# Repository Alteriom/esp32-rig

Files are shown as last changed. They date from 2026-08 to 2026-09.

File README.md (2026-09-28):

# esp32-rig










Hardware-in-the-loop testing for ESP32 firmware: a bank of real boards, a
Raspberry Pi beside them, and a service that flashes, runs a suite, captures
what the boards said and answers with a verdict.

Compile-only CI cannot catch what a radio does, what an OTA does, what a board
does after four hours, or what two boards do to each other. A rig can. This is
the software for one.

How a rig works: your CI builds a bundle, the rig flashes the boards, runs your suite and answers with a verdict

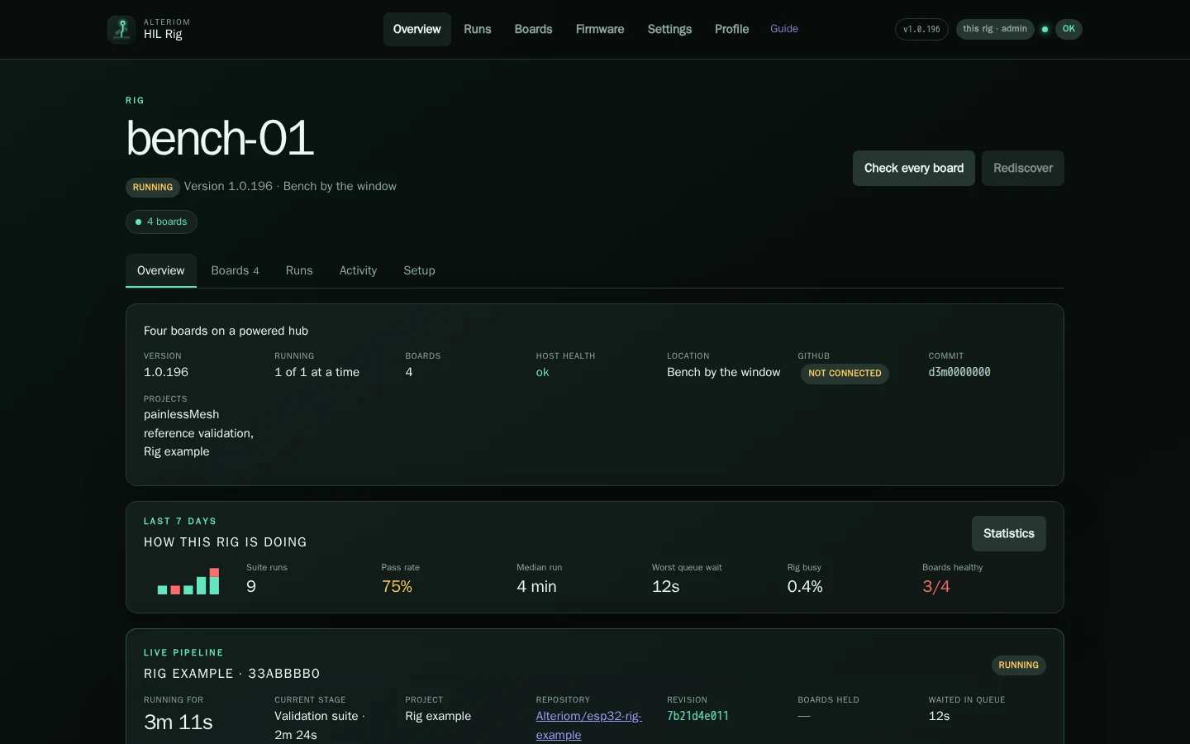
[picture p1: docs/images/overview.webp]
The rig's dashboard: its boards, its last seven days and the run in progress


Every page of the dashboard, with a picture of each:
[a tour of the dashboard](https://alteriom.github.io/esp32-rig/tour/).

## What it is

- **A service on the rig.** It queues runs, holds the boards, flashes an
  artifact your CI built, runs your suite against real hardware, captures
  every serial line and keeps the evidence. It has a dashboard.
- **A hardware abstraction layer.** Flashing, the serial console, power,
  discovery, and the pytest fixtures a suite is written against. Adding a
  board family is a description, not a rewrite.
- **A health check of its own.** Firmware the rig flashes to every board to
  answer one question before yours: is this rig fit to test on? Boots,
  serial, flash, reset, radio, wiring — per board, every release.
- **Optional: a portal.** Several rigs, one place to submit to. A rig runs
  perfectly well without one, and joining is the rig owner's choice.

## What it is not

It does not build your firmware. Your CI does that and hands the rig an
artifact with a manifest; the rig flashes exactly that and can say afterwards
precisely what it flashed. A rig with a toolchain on it is a rig that can
disagree with your CI about what "the same commit" means.

## Getting started

You need a Linux host (a Raspberry Pi 4 or 5 is what this was built on), at
least two dev boards, and a powered USB hub. **The guide** is at
[alteriom.github.io/esp32-rig](https://alteriom.github.io/esp32-rig/): [getting started](https://alteriom.github.io/esp32-rig/getting-started/)
in six steps, [what to buy and why](https://alteriom.github.io/esp32-rig/hardware/), [bring-up](https://alteriom.github.io/esp32-rig/bringup/)
in order, [the dashboard](https://alteriom.github.io/esp32-rig/dashboard/), [projects and your CI](https://alteriom.github.io/esp32-rig/projects/)
with [an example project](https://github.com/Alteriom/esp32-rig-example) to copy,
and [the API](https://alteriom.github.io/esp32-rig/api/). Its source is `docs/` here; a change to it is
published by `docs.yml`.

```bash
git clone https://github.com/Alteriom/esp32-rig
cd esp32-rig
rig/setup-runner.sh           # a virtualenv, the packages, the tools
rig/install-health-service.sh # the service, its units, udev rules
rig/verify-rig.sh             # what is missing, and what to do about it
```

Then open the dashboard, register your boards, and run the health check.

## Installing it as packages

A release is two wheels, the dashboard bundle, the Rig Health Check firmware
and a `release.json` naming each with its digest, attached to a
[GitHub release][releases]. Not PyPI yet.

```bash
base=https://github.com/Alteriom/esp32-rig/releases/download/v1.0.0
pip install   $base/alteriom_hil_core-1.0.0-py3-none-any.whl   $base/alteriom_hil-1.0.0-py3-none-any.whl
```

Both on one command line: that is what satisfies `alteriom-hil`'s dependency on
`alteriom-hil-core` without a package index.

The firmware comes with it, one bundle for every board family the rig supports,
so bringing a rig up needs no compiler and no toolchain. The firmware itself has
a repository of its own, [esp32-hil-firmware][firmware], with its own releases;
a rig release pins one (`canary/firmware.json`) and carries it. `alteriom-hil-admin
upgrade` installs and pins it, and the health check flashes what is pinned: the
same build for everyone who installs that release, which is what makes one
rig's health check comparable to another's. `--no-firmware` leaves a canary you
pinned yourself alone.

The commands it brings: `alteriom-hil-service` (the farm), `alteriom-hil-admin`
(configuration, keys, boards, providers), `alteriom-hil-health` (is this host
fit), `alteriom-hil-agent` (a rig that works for a portal), `alteriom-hil-flash`
(flash an artifact by its manifest).

A rig that already has them upgrades with the release rather than by hand:

```bash
alteriom-hil-admin upgrade --from ./dist          # a release you downloaded
alteriom-hil-admin upgrade                        # or the one your portal names
```

which checks every file against `release.json` and installs nothing if one
disagrees.

[releases]: https://github.com/Alteriom/esp32-rig/releases
[firmware]: https://github.com/Alteriom/esp32-hil-firmware
[example]: https://github.com/Alteriom/esp32-rig-example

## Writing a suite

A suite is pytest. The rig gives it a bank of boards as fixtures; what you do
with them is yours:

```python
def test_the_node_rejoins_after_a_reset(bank):
    node = bank.take("esp32-c6")
    node.reset()
    assert node.wait_for("mesh: connected", timeout=30)
```

A **profile** is the document that says where your firmware comes from, which
boards a run needs, and what to run — one file, checked in, so a run is
reproducible and a second project does not mean a second rig.

## Your project on the rig

A *project* is a GitHub repository whose firmware the rig flashes and whose
test suite it runs. A rig runs the projects it lists and no other. Two come
with the rig: the **Rig example** ([Alteriom/esp32-rig-example][example], a
small firmware and its suite -- the project to try a rig with, and to copy)
and the painlessMesh reference; both are yours to change or to remove from
the rig (and restore later). The Rig Health Check is not a project but the
rig's own firmware, installed with each release and run from Boards. Your
project needs GitHub first: the rig checks a project's repository out for
every run and fetches the firmware its CI built, and it can do neither
without a token. Give it one from the dashboard (**Settings → Rig → GitHub**,
or the Projects page while it is missing), or on the rig:

```bash
sudo alteriom-hil-admin github set     # a fine-grained token: Contents read, Actions read
sudo alteriom-hil-admin github check   # who the token is, and that GitHub accepts it
```

Until then Settings → Projects says so and offers no Add project. With it,
**Settings → Projects → Add project** asks for the repository (checked with
GitHub before anything is written), the branch a run is for by default
(empty takes the repository's own), where the pytest suite lives in it,
which chip families a run takes, and the CI workflow that builds the firmware
bundle. The rig writes the profile document under its state directory
(`/var/lib/alteriom-hil/profiles/` on a standard install), reads it back at
once, and an upgrade leaves it alone. Each project has a page there: its
configuration, the bundles the rig holds for it, its recent runs, and
**Get firmware from GitHub**, which takes the newest artifact the supply
workflow uploaded -- how a rig on a LAN, which no CI can reach, gets the
firmware its CI built. A finished run can be deleted from its page, and a
project's runs from the project's; what a run left is yours to keep or not. The same is done over the API (`GET`/`POST /api/v1/projects`,
`POST /api/v1/projects/<name>/fetch`) with an admin key. The rig does not
build firmware: your CI builds a bundle, the rig fetches it or takes it when
the CI hands it over (`POST /api/v1/artifacts`), and a run flashes it.

The rig's overview also shows the public page of the farm its software comes
from -- how many rigs and boards, how they are doing -- with a way to connect
this rig to it. Nothing there is yours; connecting is a choice, made in
Settings. `farm.public_url` in the host configuration points it at another
farm, or `off` shows none.

## Licence

Apache-2.0. The patent grant matters for a tool people run beside their own
hardware and build on.

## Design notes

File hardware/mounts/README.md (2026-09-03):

# Printable chassis

Everything that holds the rig together is generated, printable without
supports, and screws to a 330 × 272 mm base sheet (plywood, MDF, or
acrylic). Two scripts, pure Python, no dependencies:

| Script | Produces |
|---|---|
| [`generate_mounts.py`](generate_mounts.py) | the STL primitives plus `pi5-tile.stl` (Raspberry Pi 4/5, 58 × 49 hole pattern on 6 mm bosses, M2.5 screws self-tap) and `hub-strap-tile.stl` (USB hub on three zip-tie stations) |
| [`generate_chassis.py`](generate_chassis.py) | the control deck, trays and card rack described below |

STLs live in [`stl/`](stl/). Edit dimensions in the scripts and rerun
them — don't hand-edit the STLs. Holes are deliberately square: no
slicer circle-segmenting, no support, and screws and ties don't care. If
a screw hole prints tight, run the screw in once; these are self-forming
threads, not precision bores.

Why zip ties on the hub and the brick instead of screws: hubs and bricks
vary; a strap through a slot, along a groove recessed into the tile's
underside (so the tile still sits flat), and back up through the paired
slot holds any of them.

## Chassis

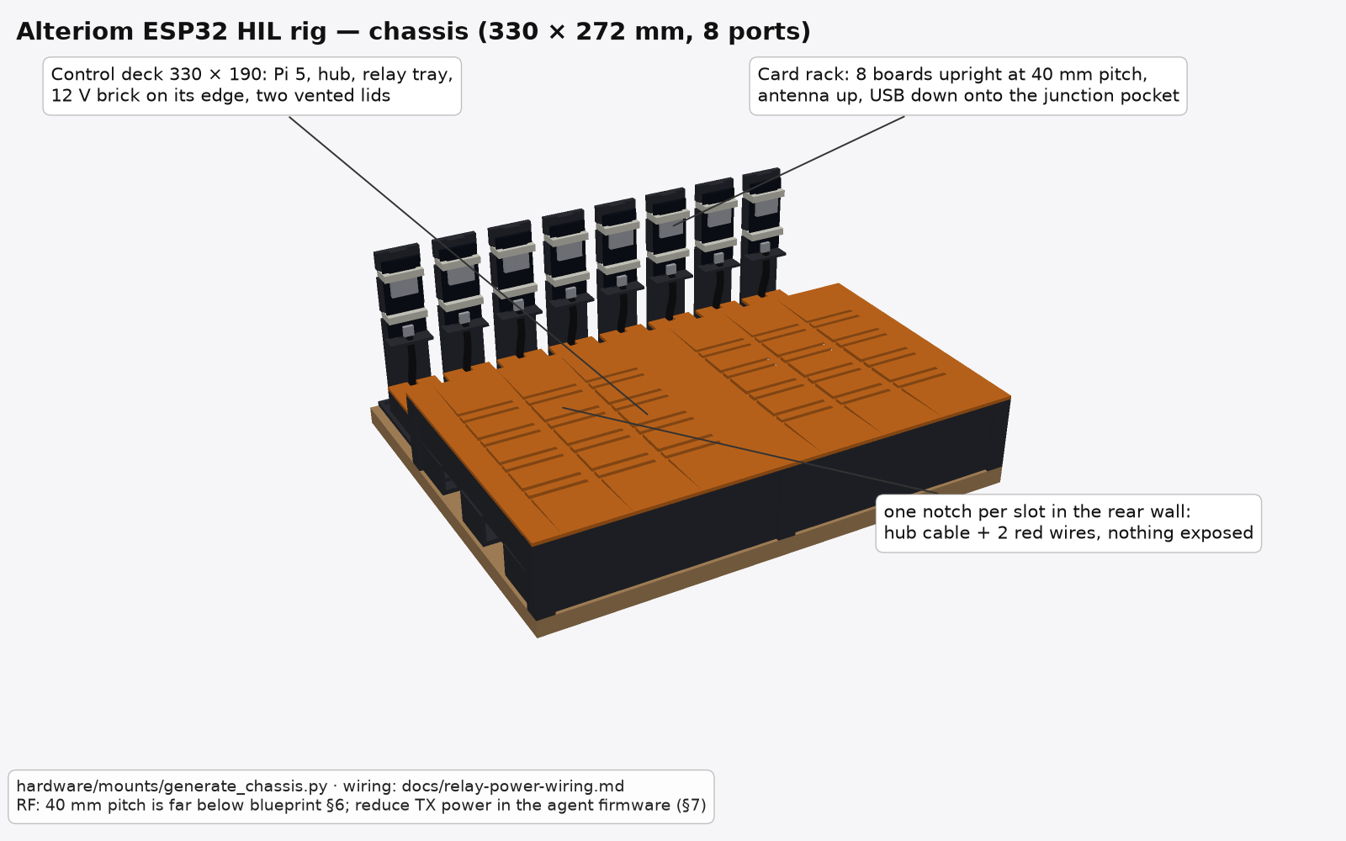
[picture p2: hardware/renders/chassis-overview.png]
Chassis overview


The relay-switched build in
[`docs/relay-power-wiring.md`](../../docs/relay-power-wiring.md) has a
relay module, a 12 V brick, sixteen red wires and a wire-nut junction per
board — the **chassis set** in [`generate_chassis.py`](generate_chassis.py)
encloses all of it. Boards stand **upright** in a card rack behind the
control deck (antenna up, USB socket down) and the brick stands **on its
edge**, so the whole eight-port rig is **330 × 272 mm** and no printed
part is longer than 178 mm (a 180 mm bed prints everything). Same rules as the tiles: pure Python, boxes only, no
supports, screw-to-base; run `python3 generate_chassis.py` after editing.

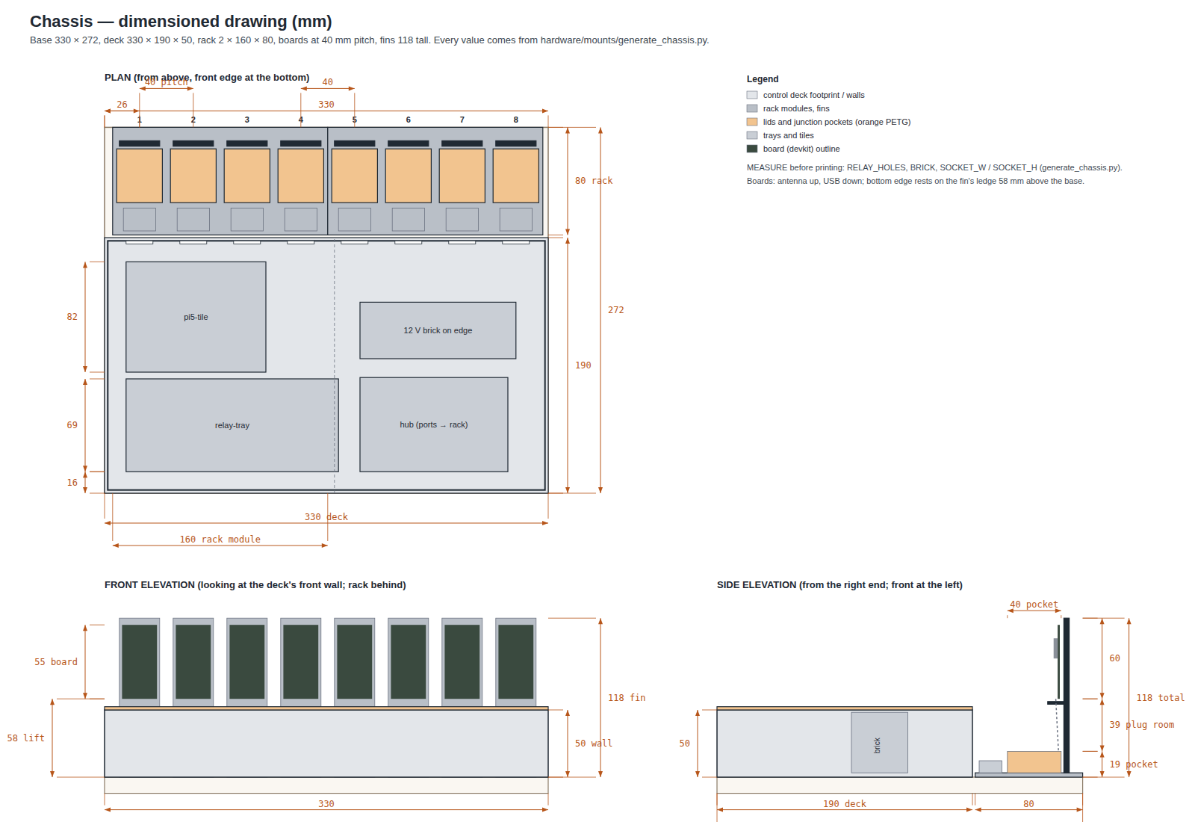
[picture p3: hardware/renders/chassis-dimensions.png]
Dimensioned drawing


Renders: [deck lids off, pockets open](../renders/chassis-deck.png) ·
[card rack](../renders/chassis-rack.png) ·
[print set](../renders/chassis-printset.png)
(from [`render_chassis.py`](../renders/render_chassis.py)); the
dimensioned drawing is [`render_dimensions.py`](../renders/render_dimensions.py),
and `python3 ../renders/build_viewer.py` writes `chassis-viewer.html`, an
interactive assembly you can orbit. All three read their numbers from the
generator.

| STL | Qty | For |
|-----|-----|-----|
| `bay-corner-post` | 4 | 12 mm post, 50 mm tall; the two walls slide into 6 mm slots; screw foot inside the corner |
| `bay-splice-post` | 2 | in-line post at the deck midline joining the two segments of a side |
| `deck-wall-long` | 2 | 159 mm front segments with a 10 mm screw flange along the inside foot |
| `deck-wall-rear` | 2 | 159 mm rear segments, one 20 × 20 mm notch per board slot: hub cable + the two red wires |
| `deck-wall-end` | 2 | 178 mm end walls, two 32 × 22 mm cable entries each (Ethernet, Pi USB-C, 12 V barrel, hub PSU) |
| `deck-lid` | 2 | 165 × 190 mm vented halves; rails underneath drop inside the walls |
| `relay-tray` | 1 | 8-channel relay module on four slotted M3 bosses (±3 mm hole-pattern tolerance) |
| `pi5-tile`, `hub-strap-tile` | 1 each | from `generate_mounts.py` |
| `psu-cradle-side` | 1 | 12 V brick standing on its long edge (100 × 30 footprint, 48 mm tall under the 50 mm wall) |
| `rack-4slot` | 2 | four upright board slots at 40 mm pitch: a 118 mm fin per board with a 12 mm rib that sits between the header rows and two strap notches, a ledge under the board's bottom edge, the junction pocket beneath it, and the USB-C socket clamp facing the deck |
| `rack-pocket-lid` | 8 | pocket lid with a notch for the male pigtail rising to the board |

**Measure before printing.** Four constants at the top of
`generate_chassis.py` are defaults for the parts in the wiring doc and
must match what you received: `RELAY_HOLES` (module hole pattern),
`BRICK` (brick length, width, thickness), `SOCKET_W` / `SOCKET_H` (the
female pigtail's overmold). Everything else is derived.

### Printing

- Structure (posts, walls, trays, rack) in a dark PETG; lids and pocket
  lids in the accent colour — the renders use charcoal and orange. Same
  0.2 mm / 3 perimeters / 20 % as the tiles; walls and lids are 2.4 mm =
  6 perimeters, so they print solid.
- **Walls**: lie on the outer face, flange pointing up. **Lids**: plate on
  the bed, rails up. **Rack**: upright, fins are 4 mm thick. **Posts**:
  upright. Nothing needs supports; the longest part is 178 mm.
- Print one `rack-4slot` first and check the socket fits its clamp, a
  board sits on the ledge with its pins clear of the fin, and the wire
  nuts clear the pocket lid before printing the second.

### Layout on the 330 × 272 mm base

Plank, MDF, or an acrylic sheet; the deck walls sit 2.4 mm in from the
edge. Coordinates are the origin (front-left corner) of each part.

| x (mm) | y (mm) | Part |
|---|---|---|
| 0–330 | 0–190 | control deck |
| 16–174 | 16–85 | `relay-tray`, terminals toward the front wall |
| 190–300 | 16–86 | `hub-strap-tile`, **ports facing the rack** |
| 16–120 | 90–172 | `pi5-tile` |
| 190–306 | 100–142 | `psu-cradle-side` |
| 6–166 and 166–326 | 192–272 | `rack-4slot` × 2; slots at x = 26 + 40·n |

Board orientation: antenna up, USB socket down, components facing the
deck. The board's bottom edge rests on the fin's ledge 58 mm above the
base so the male pigtail's plug fits between the pocket lid and the
socket. Two cable ties go around board + fin at the notches; the rib
between the header rows keeps the pins off the fin. Devkits from 25 to
29 mm wide fit; ESP8266 NodeMCU (31 mm) needs the ties only.

**RF trade-off.** Eight parallel antennas at 40 mm pitch are far denser
than blueprint §6's 0.5 m. This is the layout for flash/OTA/serial/power
coverage and bench space; for mesh-timing results, reduce TX power in the
agent firmware (§7's first RF-containment candidate) and record the
pitch in the run summary, or leave alternate slots empty for an 80 mm
pitch when a run needs it.

### Assembly

1. Screw the posts down at the deck corners and midlines, slide the walls
   in (rear segments' notches line up with the rack slots), screw every
   flange (holes every 50 mm). Cable entries on the end walls face the
   mains side.
2. Deck: relay tray front-left, hub front-right with its ports toward the
   rear wall, Pi rear-left, brick cradle rear-right, per the layout
   table. Wire the relay per the wiring doc before the lids go on; the
   GPIO ribbon and the two 12 V wires stay inside the deck.
3. Rack modules behind the rear wall, screwed to the base. Per slot: clamp
   the female pigtail (strap over it), make the wire-nut joins in the
   pocket (§6 of the wiring doc), pass the hub cable and the two red
   wires forward through the slot's notch, fit the pocket lid, strap the
   board to the fin, plug the male pigtail in from below.
4. Deck lids on. Only the boards and their antennas stand above the rig;
   every wire is under a lid.

## Scaling

One chassis = one Pi, one hub, eight ports. Growing the farm is
additive: a second chassis with its own hub on the same Pi (blueprint §8
for the per-Pi ceiling), or a second Pi runner node.

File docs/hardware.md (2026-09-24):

# Hardware

What to buy, what matters about each part, and the few rules the software
assumes you kept. A working rig is a Linux host, a powered hub, two or more
dev boards and cables that carry data. Everything else is comfort.

## The parts

| Part | What matters | Why |
|---|---|---|
| **Host**: Raspberry Pi 4 or 5 with 2 GB or more, or any small Debian or Ubuntu box | wired Ethernet; USB ports; runs Python 3.9 or newer | the rig's own Wi-Fi radio is left free for the boards to see; it reaches your LAN over the wire |
| **Host power**: the official Pi supply (27 W for a Pi 5) | never power boards from the Pi's own ports | a starved Pi throttles, and the health check will tell you so |
| **Storage**: 32 GB microSD (A2) or a small SSD | endurance is fine at this write volume | runs keep logs and serial captures; retention trims them |
| **Powered USB hub**, 7 or 8 ports, external supply of **5 V at 4 A or more** | its own supply, not the host's | boards draw more than a Pi's ports give; a starved hub is a board that "flakes" |
| **Dev boards**: esp32, esp32-c3, esp32-c5, esp32-c6, esp32-s3, esp8266, in any mix | a data-capable USB connector; see the note on two sockets below | the rig identifies each by its silicon MAC, so any family can sit on any port |
| **USB cables**, short, **data-capable**, one per board | unmodified | a charge-only cable is a board that enumerates never, or only sometimes |
| **Adapters** for micro-B boards (ESP32 DevKitC, C3-DevKitM-1, ESP8266 NodeMCU) | USB-C female to micro-B male | so every rig port can be the same |

Optional, for tests that need them:

- **Per-board power switching.** A relay module on the host's GPIO in each
  board's 5 V line, or a hub that `uhubctl` can switch. Only the power-recovery
  checks need it; reset over RTS/DTR is always available and covers most of
  what a power cut would.
- **An I/O instrument** (an ESP32 board flashed as one) wired to boards with
  jumpers, for the wiring check and for suites that drive a pin and read it
  back. See the health check page.

## Two sockets on one board

The C3, C5, C6 and S3 devkits carry two USB-C sockets: one is the chip's own
**USB-Serial/JTAG**, the other a **UART bridge**. Cable them through the one
labelled **USB**, not **UART**. A board on the UART socket still answers the
flasher during discovery, but the firmware then talks on the port the rig is
not watching, and it reads as a dead board. Discovery notes when a
native-USB family is reached through a bridge, and the health check speaks
on both, so a miscabled board is found rather than mourned.

## Rules the software assumes

- **Board identity is the silicon MAC. Port identity is the hub-port path.**
  Any family on any port; nothing is hand-labelled except, if you like, the
  port numbers on the hub. The ESP32-C5 and C6 report an 8-byte EUI-64 to the
  flasher; the rig's identity is the 6-byte base MAC.
- **Boards are USB-powered only.** Flash, serial and (with a relay) the power
  cut all ride the one USB path from hub port to board.
- **The host's Wi-Fi radio is the rig's test network.** The boards associate
  with an access point the host brings up on its own radio, so the radio
  checks prove the boards see *this* rig. Keep the host on Ethernet.
- **Antennas up, boards apart.** Boards standing upright with a few
  centimetres between them, not lying in a heap: a heap is a radio test of
  the heap.

## How many boards

Two is the minimum for anything that talks board to board. The health check
is per board and is happy with one. Six, one per family, is what the rig
software is developed against; eight is a comfortable hub.

## A chassis, if you want one

The rig this software was built on sits on a 330 × 272 mm base: a lidded
control deck for the Pi, the hub and the relay module, and a card rack that
stands eight boards upright with their antennas clear. It is about a
weekend of printing and an afternoon of assembly. Nothing in the software
depends on it; a board on a desk is a board.

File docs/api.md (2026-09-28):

# API reference

Everything the dashboard does, it does through this API, so anything you can
click you can script. JSON in and out, under `/api/v1/` on the rig (port 8090
on the host, or behind its proxy). Authenticate with a key in the
`Authorization: Bearer <key>` header. Roles: `user` reads and submits,
`admin` changes, `node` is a farm's agent.

```bash
KEY=$(sudo cat /etc/alteriom-hil/api-token)
curl -fsS -H "Authorization: Bearer $KEY" http://127.0.0.1:8090/api/v1/view | python3 -m json.tool
```

An error is `{"error": "<what went wrong, in words>"}` with a 4xx status; a
refusal by GitHub is passed through as GitHub said it.

## The rig

| | Role | Does |
|---|---|---|
| `GET /api/v1/view` | user | **the rig view**: one document with the rig's name, description, location, version, health, boards, inventory, running jobs, profiles, setup state. Contract 1. What the dashboard's rig page renders, and what a farm shows for this rig |
| `GET /api/v1/status` | user | the service's status: mode, version, queue, inventory, health, who the key is |
| `GET /api/v1/whoami` | any key | the key's name and role |
| `GET /api/v1/rig/details` | user | name, description, location |
| `POST /api/v1/rig/details` | admin | set them: `{"name", "description", "location"}` |
| `GET /api/v1/farm/public` | user | the public page of the farm the overview shows, cached; `farm.public_url: off` answers none |
| `GET /api/v1/inventory` | user | the boards and instruments as last discovered |
| `POST /api/v1/inventory/refresh` | admin | rediscover (waits for an idle rig) |
| `POST /api/v1/health` | admin | run the Rig Health Check: `{"targets": [...]}` or `{"boards": [...]}` to narrow |

## Projects

| | Role | Does |
|---|---|---|
| `GET /api/v1/projects` | user | the projects on this rig, each with its configuration, bundles and recent runs |
| `POST /api/v1/projects/inspect` | admin | `{"repo": "<url>"}`: what GitHub says about the repository, as a filled-in form with what was found and what was guessed |
| `POST /api/v1/projects` | admin | add one: `{"name", "repo", "default_ref", "suite_path", "families", "supply_workflow", "supply_artifact", "revision_key", "min_boards", "timeout_seconds"}`; everything but `repo` has a default; refused when the token cannot read the repository |
| `POST /api/v1/projects/<name>` | admin | change one, same fields |
| `POST /api/v1/projects/<name>/delete` | admin | remove it (a shipped one is tombstoned) |
| `POST /api/v1/projects/<name>/restore` | admin | bring a removed shipped project back |
| `POST /api/v1/projects/<name>/fetch` | admin | **Get firmware from GitHub**: the newest artifact of the supply workflow, checked and held; `{"reused": true}` when the rig already holds that commit |
| `POST /api/v1/projects/<name>/runs/delete` | admin | delete every finished run of the project |
| `GET /api/v1/github` | user | whether a token is set, who GitHub says it is, when it was last checked |
| `POST /api/v1/github` | admin | `{"token": "..."}`: store a token (checked with GitHub first); never shown back |
| `POST /api/v1/github/remove` | admin | forget it |

## Runs

| | Role | Does |
|---|---|---|
| `POST /api/v1/suites` | user | submit a run: `{"profile", "ref", "branch", "artifact", "targets", "boards", "tests", "keyword", "reuse", "supersede", "env", "actor"}` (on a portal also `rig`, the rig the run is for; a rig refuses it). Only `profile` matters; `ref` defaults to the project's default branch, `artifact` to the newest bundle the rig holds for that commit (none held: refused at submit, naming the workflow). Answers the run's id |
| `GET /api/v1/jobs` | user | runs, newest first, with the count behind each status: `?status=`, `?kind=` (`suite`, `inventory`), `?q=` (id, ref, summary…), `?by=` (who asked: a key's or an account's name), `?limit=`, `?offset=` |
| `GET /api/v1/jobs/<id>` | user | one run: state, stages with durations, results, the files it left |
| `GET /api/v1/jobs/<id>/artifacts/<name>` | user | one file a run left: the pipeline log, a board's serial capture, `results.xml`, the report |
| `POST /api/v1/jobs/<id>/cancel` | user | stop a queued or running run |
| `POST /api/v1/jobs/<id>/delete` | admin | delete a finished run and what it left |

A run's id is 32 hex characters. States: `queued`, `running`, `passed`,
`failed`, `cancelled`, `error`.

## Bundles

| | Role | Does |
|---|---|---|
| `GET /api/v1/artifacts` | user | the bundles the rig holds, a page at a time: id, project, commit, families, size, origin, pinned; `?profile=`, `?branch=`, `?q=`, `?limit=` |
| `GET /api/v1/artifacts/library` | user | the same, grouped by project and commit |
| `POST /api/v1/suites` | user | start a run: `{"profile", "artifact", "ref", "targets", "branch", "tests", "keyword", "boards", "rig"}`; on a portal `rig` names the rig the run is for and no other (an account's run names its own, or one shared with it); a rig, being one rig, refuses it |
| `POST /api/v1/artifacts?profile=…&repo=…&workflow=…&run_id=…&run_url=…&commit=…` | user | hand a bundle over: the body is a `.tar.gz` of the bundle directory, at most 256 MB; the query names its provenance, checked against the project's supply block; the manifest's revision key must equal `commit`. Answers the bundle's id, or `{"reused": true, ...}` for a commit already held |
| `GET /api/v1/artifacts/<id>` | user | one bundle: its manifest and provenance |
| `GET /api/v1/artifacts/<id>/bundle` · `/files/<path>` | user | download it as `.tar.gz`, or one file out of it |
| `PATCH /api/v1/artifacts/<id>/pin` · `/unpin` | admin | keep it past every prune; stop |
| `PATCH /api/v1/artifacts/<id>` | admin | `{"delete": true}`: remove one |
| `PATCH /api/v1/artifacts/prune` | admin | remove what retention would, now |

## Boards

Boards live in the inventory, which is what discovery writes.

| | Role | Does |
|---|---|---|
| `GET /api/v1/inventory` | user | every board and instrument: port, family, MAC, state, last health verdicts |
| `GET /api/v1/inventory/<board>/details` | user | the chip as the board reported it |
| `GET /api/v1/inventory/<board>/history` | user | the runs and health checks it took part in |
| `PATCH /api/v1/inventory/<board>/reserve` · `/release` | admin | `{"reason"}`: hold a board out of runs, or release it (also how quarantine is lifted) |
| `PATCH /api/v1/inventory/register` | admin | register a board by hand, as `alteriom-hil-admin boards add` does |
| `POST /api/v1/health` | admin | the Rig Health Check: `{"boards": ["<id>"]}` for one board, or nothing for all |

## Queue

| | Role | Does |
|---|---|---|
| `PATCH /api/v1/queue/pause` | admin | `{"reason": "..."}`: stop starting runs |
| `PATCH /api/v1/queue/resume` | admin | start again (a passing health check does this too) |

## Host

| | Role | Does |
|---|---|---|
| `GET /api/v1/config` | admin | the host configuration, by section, with what each setting means |
| `GET /api/v1/stats` | user | runs, pass rates and durations over time |
| `GET /api/v1/storage` · `/storage/<kind>` | user | what the rig's disk holds, by kind |
| `GET /api/v1/retention` · `PATCH /api/v1/retention/run` | admin | what retention removes on its own; run it now |
| `GET /api/v1/setup` | user | what a new rig still has to do |
| `GET /api/v1/keys` | admin | who holds a key, by name and role; never a key |
| `GET /api/v1/sessions` · `POST /api/v1/sessions/revoke` | user | the browser sessions signed in with this key; end one |

Keys themselves are made and revoked on the host:

```bash
sudo alteriom-hil-admin keys create --name ci-bundles --role user    # printed once
sudo alteriom-hil-admin keys list
sudo alteriom-hil-admin keys revoke --name ci-bundles
```

## Webhooks

| | Role | Does |
|---|---|---|
| `GET /api/v1/webhooks` | admin | where this rig's events go; the secret is never among them |
| `PATCH /api/v1/webhooks` | admin | `{"url", "secret", "events": [...]}`: add one; deliveries are signed with the secret when given |
| `PATCH /api/v1/webhooks/<id>` · `…/<id>/test` · `DELETE /api/v1/webhooks/<id>` | admin | change, send a test event, remove |
| `GET /api/v1/webhooks/<id>/deliveries` | admin | what was sent and what came back |

The same events go to the channels `alteriom-hil-admin notify` sets up.

## The command line

`alteriom-hil-admin` on the host does what the API does and a little more,
under `sudo` for anything that writes:

| Command | Does |
|---|---|
| `status` | the saved or live health snapshot |
| `config show` · `validate` · `set <key> <value>` · `apply` | the host configuration |
| `config join --portal … --token …` | make this host a node of a farm |
| `github set` · `check` · `remove` | the GitHub token |
| `keys list` · `create` · `revoke` | API keys |
| `boards list` · `discover` · `add` · `remove` · `validate` | the board registry |
| `instruments list` · `add` · `wire` · `unwire` · `probe` · `remove` | test equipment and its jumpers |
| `health refresh` | a fresh host health snapshot |
| `upgrade [--from DIR] [--no-firmware] [--dry-run]` | install a release |
| `backup create` · `list` · `restore [--apply]` | the nightly backup, by hand |
| `notify set` · `show` · `test` · `tune` · `remove` | where the rig says it broke |
| `providers set` · `show` · `check` · `test` · `remove` | real services the rig validates with your credential |
| `service` | the Actions runner service, on a rig that has one |

## The MCP server

The rig also speaks the Model Context Protocol, so an assistant can ask it
what is running, read a failure, or submit a run with the same key and the
same roles. [MCP](mcp.md) has the tools and how to connect.

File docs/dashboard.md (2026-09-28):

# The dashboard

The rig's own web page, served by the rig at port 8090 (or behind its
reverse proxy). Six pages in the header: **Overview**, **Runs**, **Boards**,
**Firmware**, **Settings** and your **Profile**. Sign in with a key; the key
stays in that browser tab and nowhere else. [A tour of the dashboard](tour.md)
shows every page with a picture.

The same pages, rendered from the same rig-view document, are what a farm
shows for this rig once it is connected. What you see here is what the farm
sees, no more.

## Overview

The Overview page

The rig's own page. Its name, description and location as written in
Settings; its version; its health in a word with what is not ok up front,
and every check behind one click; the run in progress with its live stages;
what needs attention; recent runs; the boards. **How this rig is doing** is
the last seven days in one line, and **Statistics** opens the whole history.
At the bottom, the public page of the farm the rig software comes from, with
a way to connect this rig to it. Nothing there is yours; connecting is a
choice made in Settings.

## Runs

**New run** at the top: choose the project, the bundle to flash (the ones the
rig holds for that project, newest first; **Get firmware from GitHub** on the
project's page fetches a new one), which boards or families, and under
**Test selection** a pytest keyword or a list of test files to narrow the
suite. **Run**.

Below, every run the rig has made, newest first, searchable, with its
verdict, project, commit, boards, duration and **who asked for it**, linked
to their [profile](#profile).

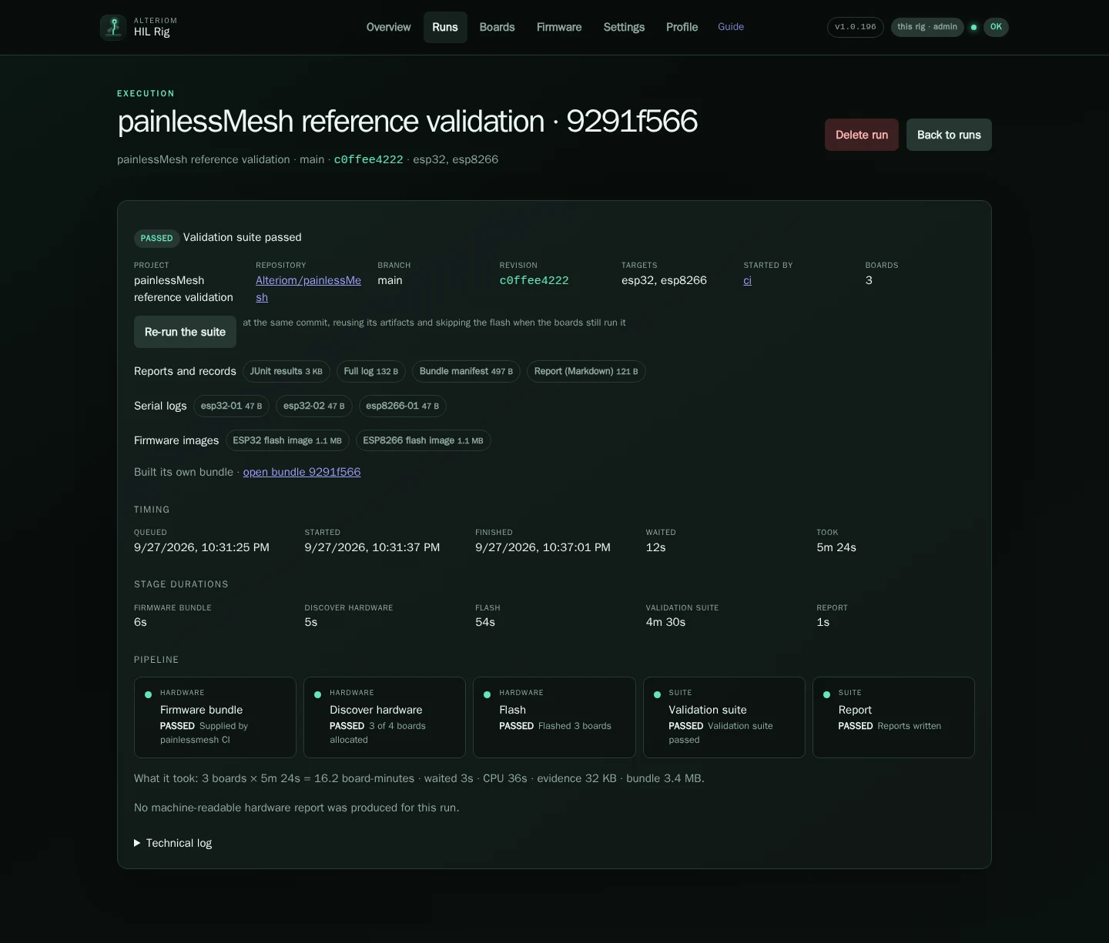
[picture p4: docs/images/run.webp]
A run's page


A run's page has:

- **the pipeline** — checkout, discover, flash, preflight, suite, report,
  each with its duration and log;
- **the results** — every test, per board where the suite is per board,
  with the failure text;
- **the evidence** — the pipeline log, one serial capture per board, the
  JUnit file, the report, each downloadable;
- **cancel** while it runs, **delete** once it has finished. What a run left
  is yours to keep or not.

The queue's state is at the top of the page: paused by a red health check
with the reason, or by you; resume from there.

## Boards

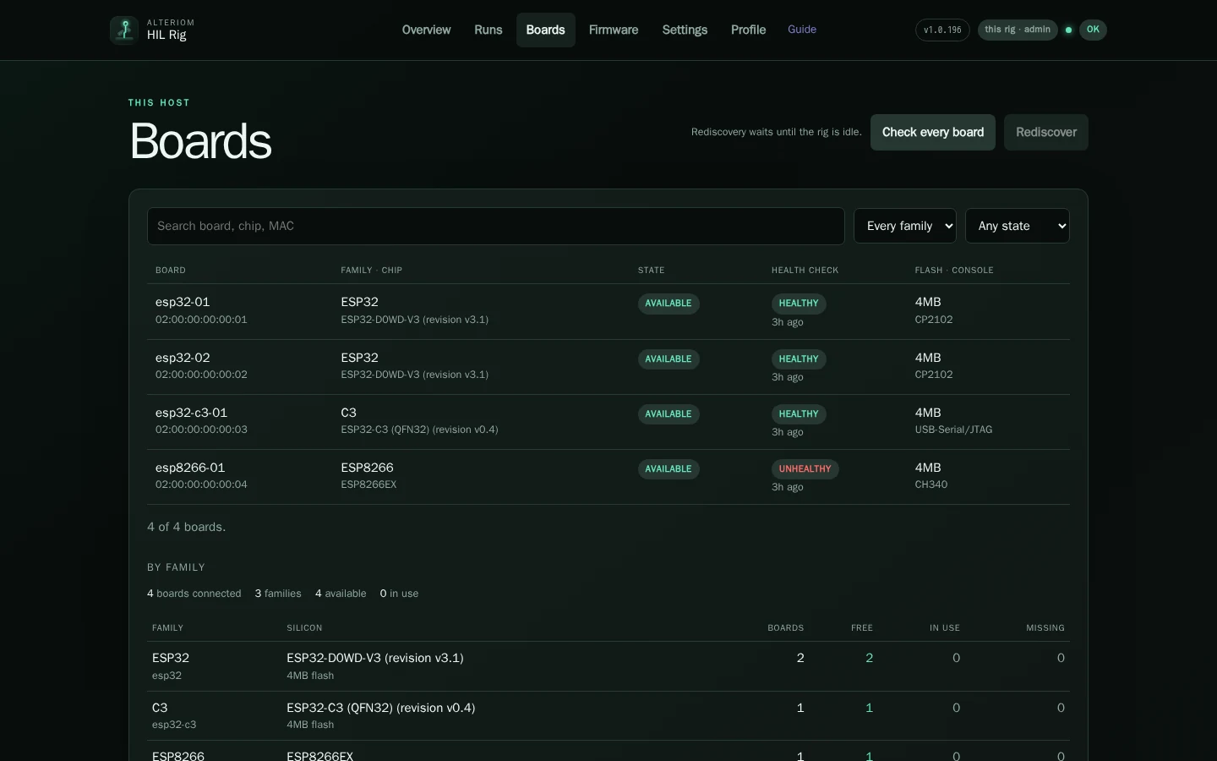
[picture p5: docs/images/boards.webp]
The Boards page


Every board the rig knows: name (family and the last four characters of
its MAC), family, port, state (idle, held by a run, quarantined, red on a
check), the last health check's verdict per check, and the chip it reported
(model, revision, cores, flash size). Filter by family and state; search.

**Rediscover** opens every port and reads every chip again; it waits for the
rig to be idle, since a discovery resets boards a run may be holding.
**Run the Rig Health Check** checks every board. A board's own page has its
chip in full, its health check history, the runs it took part in, and a check
of that one board.

Instruments (test equipment wired to boards) appear here too, with their
wiring. Register one with `alteriom-hil-admin instruments add`, and each
jumper with `instruments wire`.

## Firmware

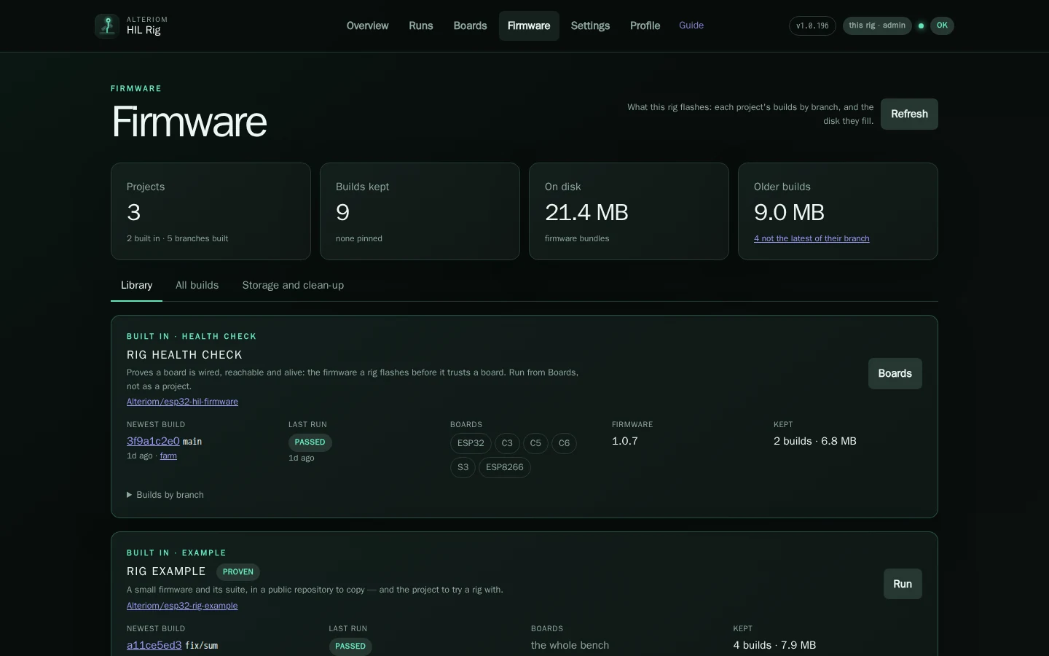
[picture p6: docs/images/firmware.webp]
The Firmware page


**Library** is one card per project: the newest build of each branch and who
it came from, the last run on it, the families it holds and what it keeps on
disk. **All builds** is every bundle the rig holds, one row each: the project,
the commit, the families, the size, when it arrived and how (fetched from
GitHub, handed over by a CI, installed with a release), and whether it is
**pinned**. The health check's bundle is pinned by the release that installed
it. **Storage and clean-up** says what older builds cost and prunes them:
retention removes old unpinned bundles, and a pinned one outlives every
prune. Download a bundle or delete one from its page.

## Statistics

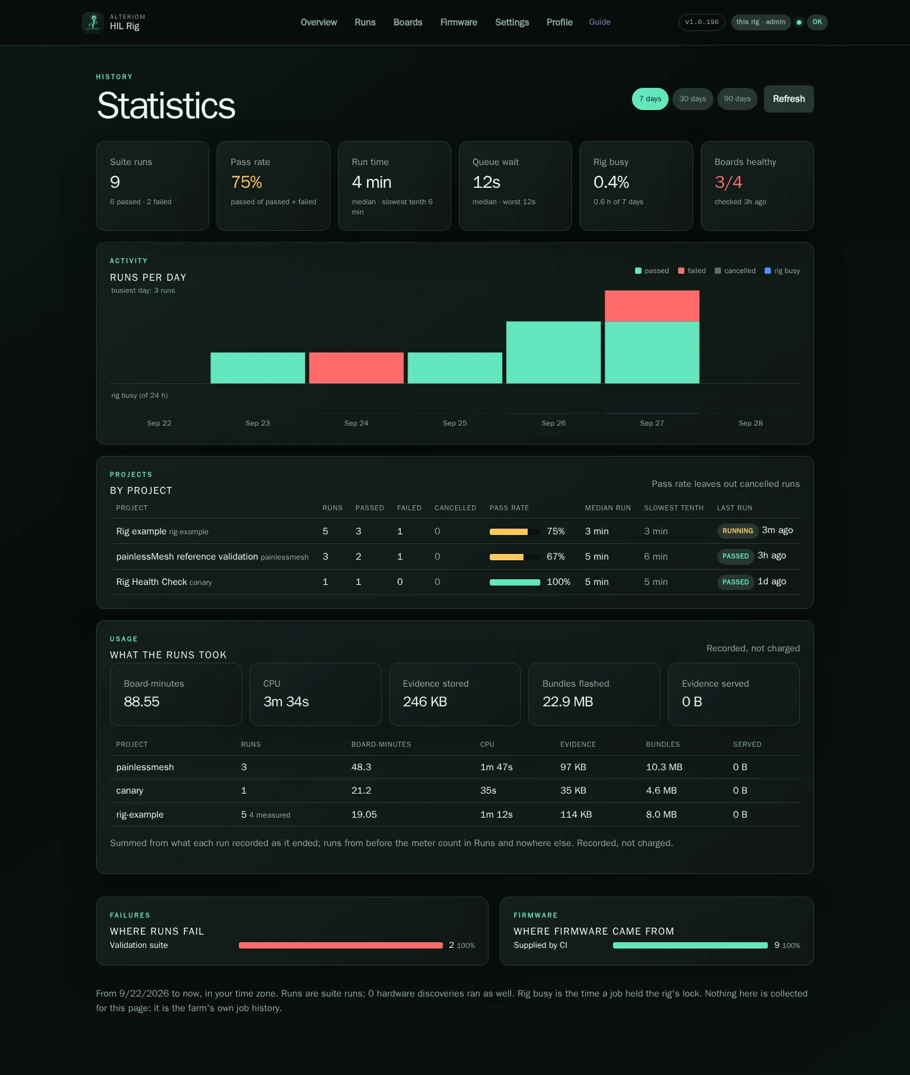
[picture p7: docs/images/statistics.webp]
The Statistics page


Opened from Overview. Seven, thirty or ninety days: suite runs, pass rate,
median and slowest run, queue wait, how busy the rig was and how many boards
are healthy; runs per day by verdict; each project's runs and pass rate; what
the runs took (board-minutes, CPU, evidence and bundle bytes, recorded and
never charged); which stage failures come from; and where the firmware came
from. All of it is the rig's own job history.

## Profile

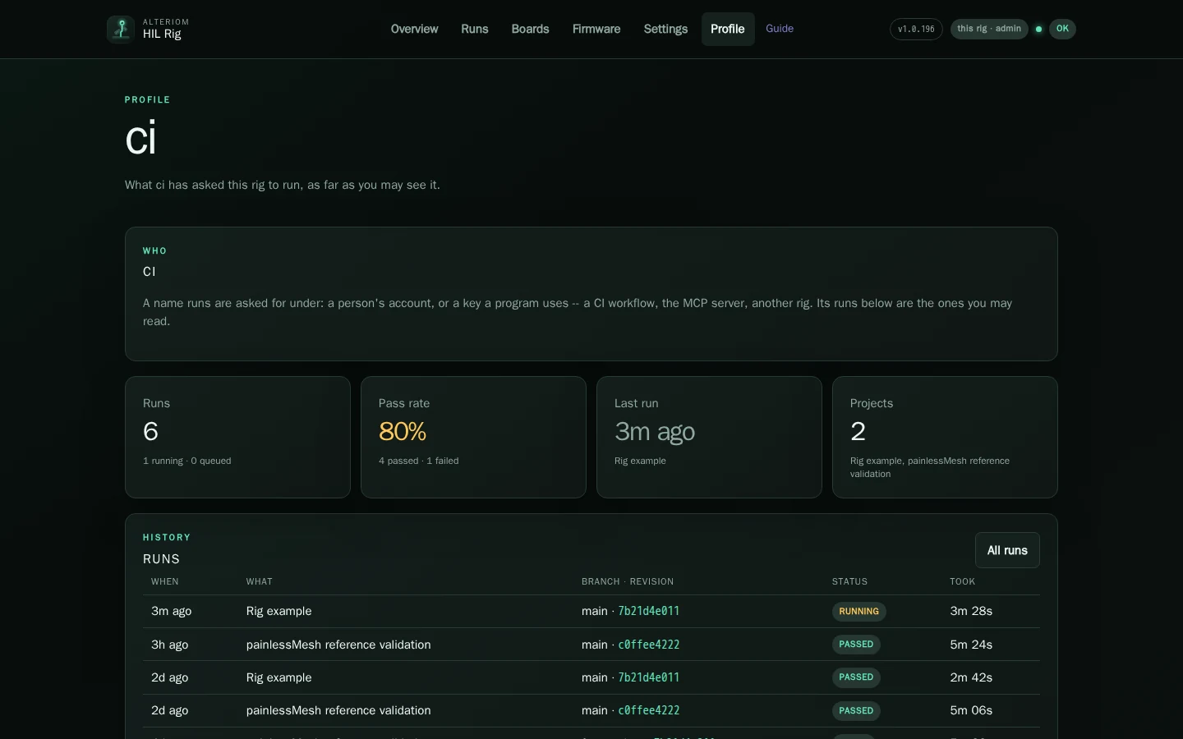
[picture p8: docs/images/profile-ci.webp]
A CI key's profile


Every name a run was asked for under has a profile at `#profile/<name>`: a
person's key, a CI's key, a farm account. It shows that name's runs (only
the ones you may see), its pass rate, its last run and the projects it ran;
the **by** link on any run opens it. The runs behind it are
`GET /api/v1/jobs?by=<name>`.

**Profile** in the header is yours: who the rig says you are, your role and
what it allows, how you signed in, your own runs, and **Forget this key**.
Signed in with a key, it also shows **Use this key from a workflow**: the
request a CI job sends to run a suite, with this rig's address in it. Give
each CI its own `user` key (Settings → Access), named after the workflow; its
runs then have a profile of their own, and revoking it touches nothing else.

## Settings

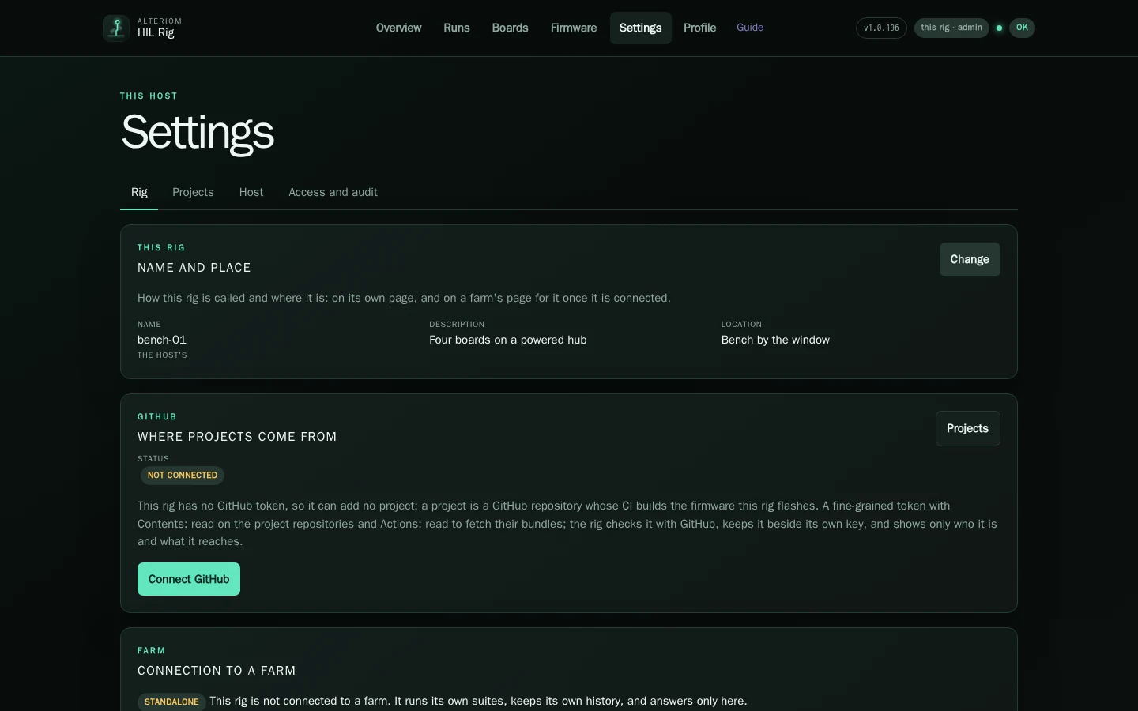
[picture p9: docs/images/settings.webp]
Settings, Rig page


Four pages on a rig, one purpose each.

**Rig** — the rig's name, description and location (what its page shows,
here and on a farm); **GitHub**, the token the rig reads projects and their
bundles with: who it is according to GitHub, what kind it is, when it
expires, where it came from, which repositories it reaches and what it may
do with each project's, as a status block with a per-project table; **Check
again**, **Details** (the whole picture: the private repositories it was
given, the public ones it sees, what GitHub refused and why), **Replace
token** (the form appears only then) and, for a token given from the page,
**Forget it**; **Connection to a farm**, connect, what is
shared, disconnect; **Software**: the version installed, the newest release
(from GitHub's releases of the rig software, or from the farm a node
belongs to), **Check for updates**, **Install** when one is newer, and
**Install updates automatically**, off until you turn it on. A rig is never
updated because a farm said so: the farm's release is offered until you
install it, from either page, or turn automatic installs on.

**Projects** — the projects this rig runs and no other. Each has a page:
its configuration (repository, default branch, suite path, families, the
supply workflow and artifact name), the bundles the rig holds for it, its
recent runs, **Get firmware from GitHub**, edit, remove. **Add project**
starts from a repository URL: the rig looks it up on GitHub and fills the
form in, saying what it found and what it guessed. A shipped project
(the Rig example, and painlessMesh, the reference) can be removed and later restored. The Rig
Health Check is not a project: it comes with the release and is run from
Boards. [Projects and your CI](projects.md) has the whole story.

**Host** — the host configuration the rig runs with, by section: the queue's
concurrency, the health thresholds, quarantine, retention, backup, the
gateway network, the broker, notifications. Each setting shows its value and
what it means; the ones the service reads at start say so. The same document
is `/etc/alteriom-hil/config.yaml`, edited with `alteriom-hil-admin config
set`.

**Access** — the API keys: the rig's own, and the ones you made, each with
its role (`admin`, `user`, `node`) and when it was last used. Create one
(shown once), revoke one. Sessions signed in with a key, and a way to revoke
them.

## Keys and roles

| Role | May |
|---|---|
| `user` | read everything the rig shows; submit a run |
| `admin` | everything: projects, settings, keys, the GitHub token, deleting runs and bundles, draining the rig |
| `node` | what a farm's agent needs, and nothing a person does |

The rig's own key (`/etc/alteriom-hil/api-token`) is an admin. Make a `user`
key for a browser you do not administer from, and a separate key per CI
that hands bundles over, so one can be revoked without the other.

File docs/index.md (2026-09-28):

# Alteriom HIL Rig

A hardware-in-the-loop rig for ESP32 firmware: a Raspberry Pi, a powered USB
hub and a handful of dev boards that flash the firmware your CI built, run
your test suite against real silicon, and keep the evidence. It works on its
own, on your bench, with its own dashboard; it can also connect to a farm and
take work from there.

The rig's dashboard: its boards, its last seven days and the run in progress

<div class="grid cards" markdown>

- **[Getting started](getting-started.md)** — from a box of parts to the first
  green health check, in about an hour.
- **[Projects and your CI](projects.md)** — how the rig gets *your* firmware and
  runs *your* suite: the project, the bundle, the workflow, the example.
- **[The dashboard](dashboard.md)** — what every page shows and what it is for,
  and [a tour](tour.md) of it in pictures.
- **[API reference](api.md)** — every route the rig answers.

</div>

## What it is

How a rig works: your CI builds a bundle, the rig flashes the boards, runs your suite and answers with a verdict

- **A rig runs the projects you give it and no other.** A project is a GitHub
  repository: the rig checks it out for each run, flashes the bundle its CI
  built, runs its pytest suite over the boards, and keeps the run as
  evidence — logs, serial captures, JUnit, a report.
- **The rig does not build firmware.** Your CI does, the way it already does,
  and hands the bundle over — or the rig fetches it from GitHub, which is how
  a rig on a home LAN, reachable by no CI, still gets its firmware.
- **It proves its own hardware first.** The Rig Health Check flashes every
  board with a small firmware of its own and asks each one: do you boot, is
  your serial path clean, does your flash keep a value, can I reset you, do
  you see my network. A red health check is never your regression.
- **GitHub is where projects come from.** A rig without a GitHub token can add
  no project; with one — a fine-grained token that reads your repositories
  and their Actions artifacts — adding a project is pasting its URL.
- **Standalone first, connected when you want.** The rig's dashboard is the
  rig's. Connecting it to a farm gives it a page there too, the same page,
  and lets the farm hand it runs.

## Where things are

| | |
|---|---|
| The rig software | [Alteriom/esp32-rig](https://github.com/Alteriom/esp32-rig) — releases are two wheels, the dashboard bundle and the pinned health check firmware |
| The health check firmware | [Alteriom/esp32-hil-firmware](https://github.com/Alteriom/esp32-hil-firmware) — its own repository, its own releases; the rig pins one |
| An example project | [Alteriom/esp32-rig-example](https://github.com/Alteriom/esp32-rig-example) — the smallest project a rig can run, with the workflow that builds its bundle |
| The reference project | [painlessMesh](https://github.com/Alteriom/painlessMesh) — the mesh library this rig was built to validate; ships with the rig, removable |

Apache-2.0. Issues and pull requests on the repository.

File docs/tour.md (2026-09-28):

# A tour of the dashboard

What a rig looks like once it has boards and a week of work behind it. Every
picture on this page is the real dashboard, taken of a demo rig: four boards
on a powered hub, three projects, a CI key and a person running suites. The
names, runs and boards are made up; [the recipe](#how-these-pictures-are-made)
is at the bottom, and anyone can take them again.

How a rig works: your CI builds a bundle, the rig flashes the boards, runs your suite and answers with a verdict

## Overview: the rig at a glance

The Overview page: the rig's name, version and location, its health, the last seven days and the run in progress

The rig's own page. Its name is the host's; the description and location are
yours, from **Settings → Rig**. Under them, the facts that answer "is this rig
fine": the version installed, how many runs it takes at a time, its boards,
the host's health, whether GitHub is connected and which projects it runs.

**How this rig is doing** is the last seven days in one line: suite runs per
day, the pass rate, the median run, the worst wait in the queue, how busy the
rig was and how many boards passed their last health check.
**Statistics** opens the whole picture. Below it, the run in progress, stage
by stage, as it happens.

## Runs: every run, newest first

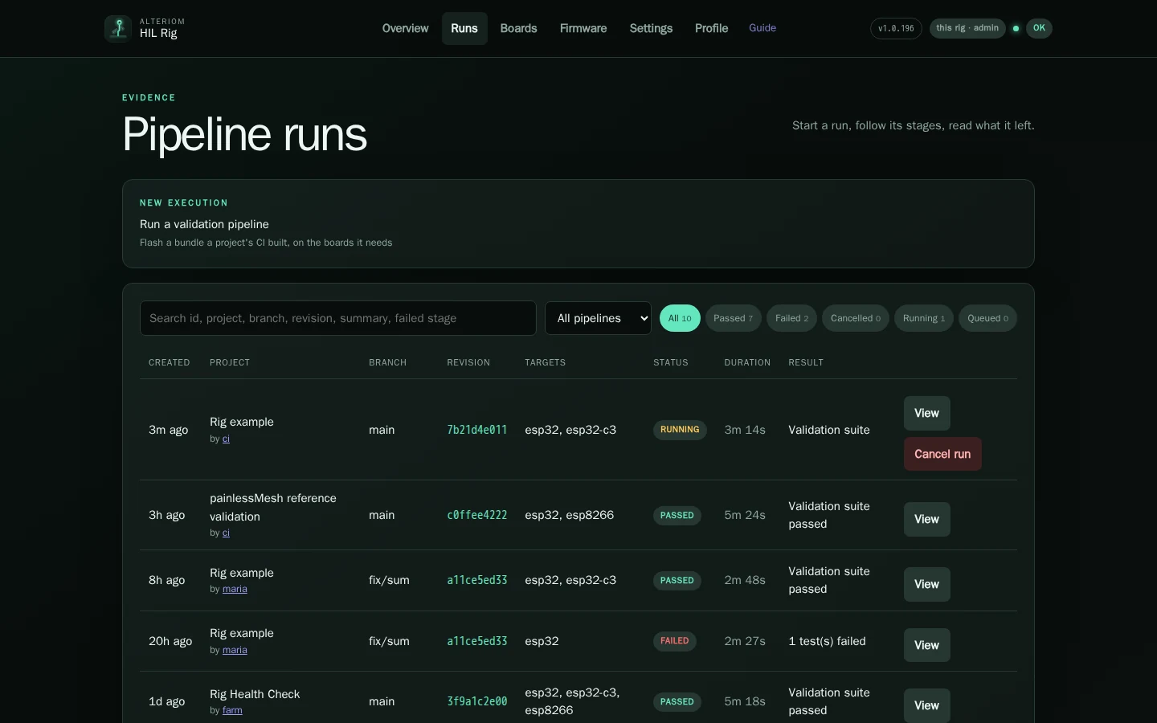
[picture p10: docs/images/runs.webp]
The Runs page: a search box, filters by status, and a table of runs with who asked for each


Every run the rig has made. Each row says what it was for, the branch and
commit, the boards' families, the verdict and how long it took, and **who
asked**: the key or account it came from. That name is a link to its
[profile](#profiles-who-asked-and-what-they-ran). Search by id, project,
branch, commit or failed stage; filter by status.

## A run: the pipeline and the evidence

A passed run: its project, commit and boards, the evidence to download, timing per stage and the pipeline

One run, start to finish. At the top, the verdict and the facts behind it:
project, repository, branch, commit, targets, who started it and how many
boards it held. Then the evidence, each file downloadable: JUnit results, the
full log, the bundle's manifest, the report, one serial capture per board and
the firmware images that were flashed. **Timing** and **Stage durations** say
where the minutes went; **What it took** is the run's meter: boards times
minutes, CPU, and the bytes it kept.

A failed run reads the same way, with the failing stage marked and its
failure text up front.

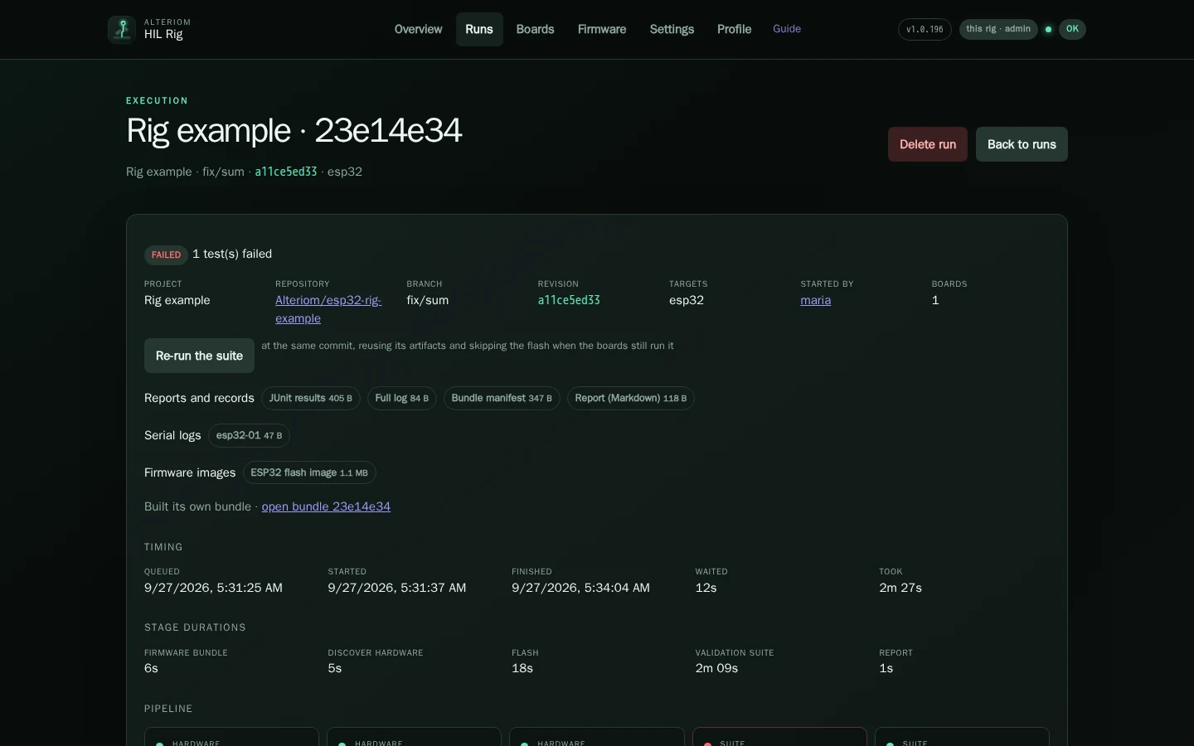
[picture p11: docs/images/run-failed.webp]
A failed run: one test failed, with the same evidence and a Re-run button


**Re-run the suite** runs it again at the same commit, reusing its bundle and
skipping the flash when the boards still run it.

## Boards: what is on the hub

The Boards page: four boards with their chip, state, health check verdict and flash size

Every board the rig knows: its name and MAC, its family and the chip it
reported, whether it is free or held by a run, its last health check verdict
and when, and its flash and USB bridge. Here the ESP8266 failed its radio
check; it stays out of runs until a check passes again. **Check every board**
runs the Rig Health Check; **Rediscover** reads every port again once the rig
is idle. Below, the same boards by family.

## Firmware: the bundles the rig holds

The Firmware page: projects with their newest build, last run and what they keep on disk

What the rig flashes, by project: the newest build of each branch and who it
came from, the last run on it, the families it holds, and how much it keeps
on disk. The health check's firmware arrives with each release. **All
builds** lists every bundle; **Storage and clean-up** says what a prune would
free and does it.

## Statistics: how the rig has been doing

The Statistics page: runs per day, pass rate by project, what the runs took, and where they fail

Seven, thirty or ninety days of the rig's history: runs per day by verdict,
each project's pass rate and run times, what the runs took in board-minutes,
CPU and storage, which stage failures come from and where the firmware came
from. It is computed from the rig's own job history; nothing is collected for
it.

## Profiles: who asked, and what they ran

A CI key's profile: its runs, pass rate, last run and projects

Every name a run was asked for under has a profile: a person's key, a CI's
key, a farm's account. It shows that name's runs as far as you may see them,
its pass rate, its last run and the projects it ran. Reach one from the
**by** link on any run.

**Profile** in the header is your own: who the rig says you are, your role
and what it lets you do, how you signed in, and your runs.

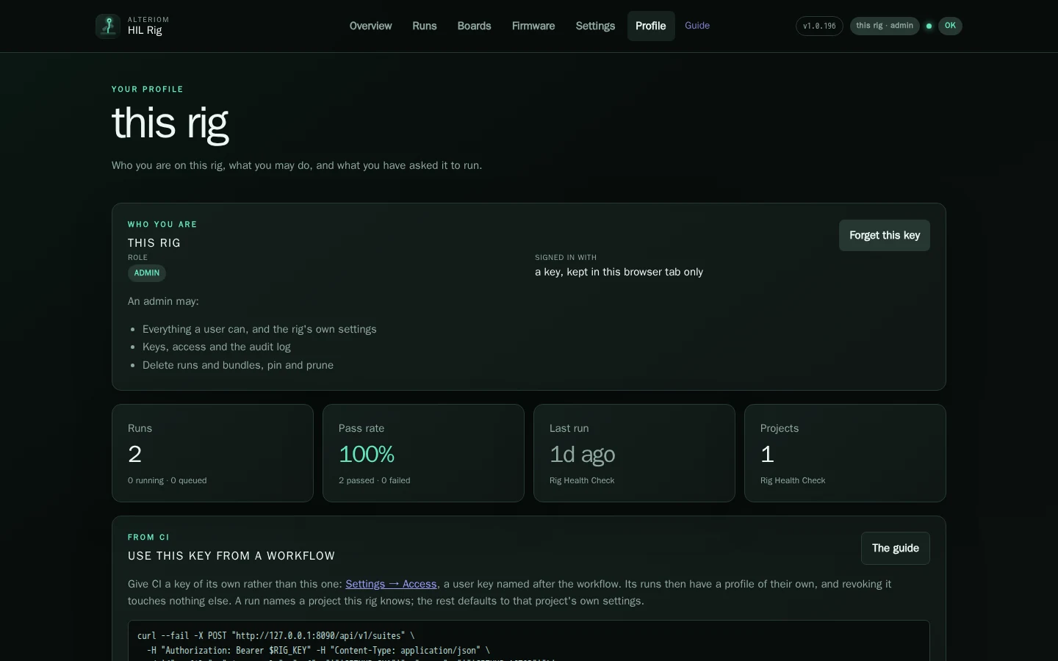
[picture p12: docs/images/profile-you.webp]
Your own profile: your role and what it allows, your runs, and how to run a suite from CI


With a key, it also has **Use this key from a workflow**: the exact request a
CI job sends to run a suite, with this rig's address filled in. Give each CI
its own `user` key from **Settings → Access** rather than the rig's admin key:
its runs then have a profile of their own, and revoking it touches nothing
else. [Projects and your CI](projects.md) has the whole workflow.

## Settings

Settings, Rig page: the rig's name and place, the GitHub connection and the connection to a farm

Four pages: **Rig** (its name and place, GitHub, a farm, the software),
**Projects**, **Host** and **Access and audit**. [The dashboard](dashboard.md#settings)
says what each setting does.

## On a phone

<div class="grid" markdown>

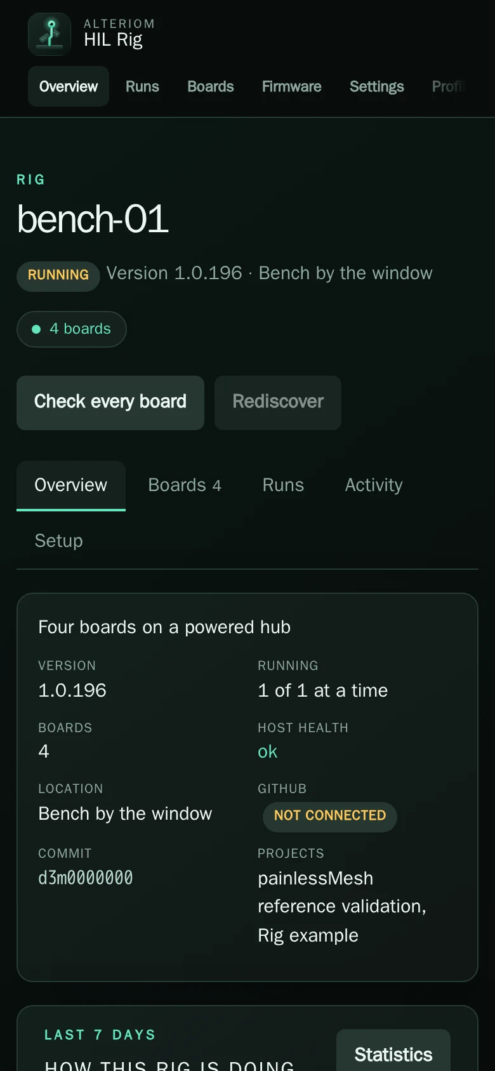
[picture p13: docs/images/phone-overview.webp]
The Overview page on a phone


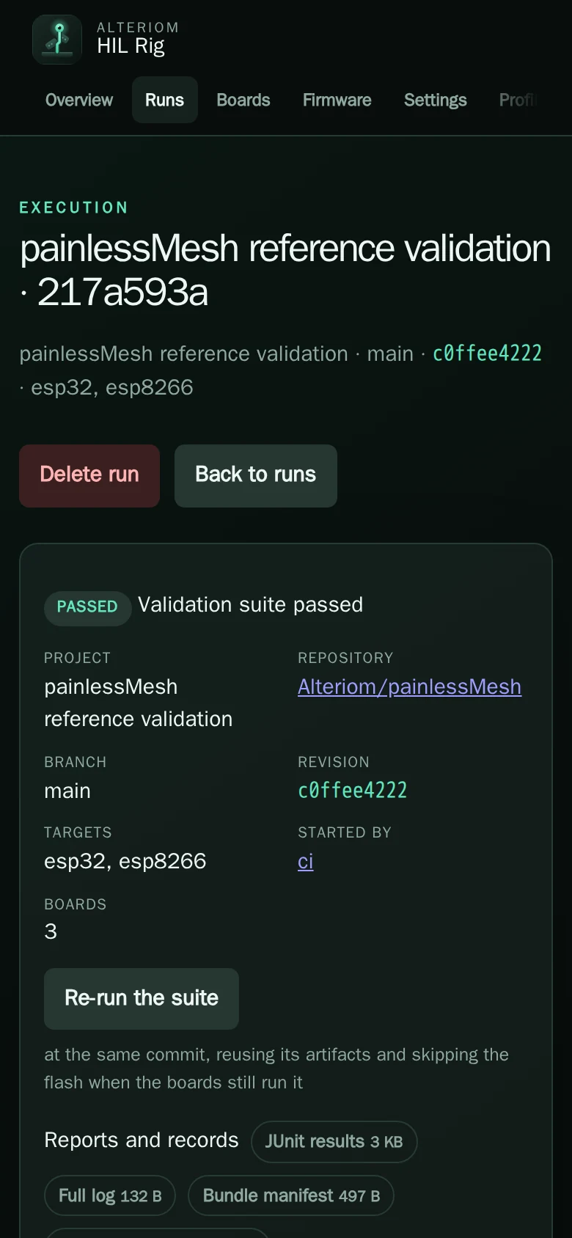
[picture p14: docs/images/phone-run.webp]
A run on a phone


</div>

The same pages at phone width: the menu scrolls sideways, facts stack in two
columns and a page's buttons move under its title.

## How these pictures are made

The pictures are taken by a script, of a demo rig, so they can be taken again
after any change to the dashboard. The demo is the real service on a state
directory written by `runner/screenshots/demo_rig.py`; nothing in it touches
hardware. `runner/screenshots/README.md` has the recipe.

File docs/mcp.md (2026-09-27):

# The farm's MCP server

An assistant that can read the farm answers "what is the farm doing", "why did
that run fail", "which bundle did it flash" and "is this board healthy" from
the farm itself, rather than from somebody pasting dashboard pages into a
chat. `alteriom-farm-mcp` is that reader: a [Model Context
Protocol](https://modelcontextprotocol.io) server over stdio, which turns each
tool call into a read of the farm's API with a named key. It is step 6 of
read-only first.

## Read-only, on purpose

Every tool reads. None starts a run, cancels one, pins or deletes a bundle, or
touches a board — and the client it is built on
(`alteriom_hil.farm_client`, in the rig's core package) cannot
build a request that would. Tools that change the farm come after this has
been used, and will need a key whose role allows them: the farm refuses those
routes to a `user` key whatever a client asks
([keys and roles](dashboard.md#keys-and-roles)). A **`user` key is all
this needs**, and it is the key to give it — never the farm's token.

## Set it up

On the farm host, a key for the assistant:

```bash
sudo alteriom-hil-admin keys create --name assistant --role user --note "MCP"
```

On the machine the assistant runs on, the HAL installed (it brings the
`alteriom-farm-mcp` command) and the key in a file only you can read:

```bash
pip install -e ./core -e ./rig
install -m 0600 /dev/null ~/.config/alteriom/farm-key && $EDITOR ~/.config/alteriom/farm-key
```

Then register it with the client. For Claude Code:

```bash
claude mcp add alteriom-farm \
  --env ALTERIOM_FARM_URL=https://hil.example.com \
  --env ALTERIOM_FARM_KEY_FILE=$HOME/.config/alteriom/farm-key \
  -- alteriom-farm-mcp
```

`ALTERIOM_FARM_URL` is where the dashboard is served — through the TLS proxy
or a tailnet ([reaching the dashboard](bringup.md#7-reach-the-dashboard)). The
client refuses plain `http` to anything but loopback, since a key sent in the
clear is a key given away. `ALTERIOM_FARM_KEY` works in place of the file, for
a client that injects secrets as environment.

## Tools

| Tool | Answers |
|---|---|
| `farm_whoami` | the name and role of the key it reads with |
| `farm_status` | health and what is wrong with it, the queue, boards connected and missing, the ten latest runs |
| `farm_devices` | every board — family, state, the run holding it, its last Rig Health Check verdict (the `canary` profile) and what failed — plus missing and unregistered devices and instruments |
| `farm_capacity` | boards per family — connected, free, in use, and the tags the free ones carry — and how many runs may run at once, are running and wait: whether a run asking for one esp32-c3 would start now |
| `farm_runs` | runs newest first, filtered by status, kind or a search |
| `farm_run` | one run's stages and where it stopped, the failure detail, each capability's verdict, the failed tests, its bundle and its evidence |
| `farm_run_log` | the last lines of a run's log |
| `farm_bundles` | the bundles the farm holds, by profile or search |
| `farm_bundle` | one bundle: manifest, images, files, the runs that flashed it |
| `farm_statistics` | runs and pass rate, run time, queue wait, rig busy, failures by stage, per project |

Results are cut to what a question needs — a run's page is tens of kilobytes of
report and log, and `farm_run` returns its stages, verdicts and failures, with
`farm_run_log` for the log — and capped at 60 KB. A wrong argument, a key the
farm refuses or a farm that cannot be reached comes back as a result the model
can read (`isError`), not a broken session.

## Protocol

JSON-RPC 2.0, one message per line on stdin and stdout, logging on stderr.
`initialize` (protocol versions 2025-06-18, 2025-03-26 and 2024-11-05),
`ping`, `tools/list` and `tools/call`; notifications are accepted and not
answered. Written against the protocol directly rather than an SDK: the HAL
supports Python 3.9 and the protocol this needs is small.

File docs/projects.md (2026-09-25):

# Projects and your CI

How the rig gets *your* firmware and runs *your* suite. Two things live in
your repository: a CI job that builds a **bundle**, and a **pytest suite**
that the rig runs against the boards. The rig adds the project by its URL,
fetches the bundle its CI built, checks the suite out for each run, flashes,
runs, and keeps the evidence.

The smallest working project is
[Alteriom/esp32-rig-example](https://github.com/Alteriom/esp32-rig-example):
a firmware that answers the rig, a suite of three tests, and the workflow
that builds the bundle. Fork it, or copy the three pieces into your project.

## 1. GitHub first

The rig needs a token to read your repository and its Actions artifacts. A
fine-grained personal access token with **Contents: read** and **Actions:
read** on the repositories you will test. Give it to the rig under
**Settings → Rig → GitHub**, or on the host:

```bash
sudo alteriom-hil-admin github set      # reads the token from the terminal, never from argv
sudo alteriom-hil-admin github check    # who the token is, and that GitHub accepts it
```

The token is kept on the rig (`/var/lib/alteriom-hil/github-token`, readable
by the rig's user only) and is never shown back. What the rig does show, on
that card, is everything else about it: who GitHub says it is, what kind of
token it is (fine-grained or classic), **when it expires** (with a warning on
the Overview two weeks ahead), where it came from (this page, or the host's
file), **which private repositories it was given** (GitHub shows every
public repository to any token, so those are counted apart), and, per
project, whether it can see the repository, read its code, and list its
Actions artifacts. **Check
again** asks GitHub now, after you changed the token there. Without a token,
**Add project** is not offered: a rig cannot add a project it cannot read.

!!! tip "A fine-grained token reaches only the repositories you gave it"
    When adding a project is refused, the refusal names the private
    repositories the token was given and where on GitHub to add the new one
    (the token's *Repository access*). Widening the token is done on GitHub; the rig then
    sees it on the next check.

## 2. Add the project

**Settings → Projects → Add project.** Paste the repository's URL, press
**Look it up**. The rig asks GitHub about the repository with its token and
fills the form in: the default branch, where the pytest suite seems to live,
which workflow looks like the one that builds firmware, and which board
families the workflow builds for. It says which of those it found and which
it guessed; check them and press **Add**. The fields:

| Field | Meaning | Default |
|---|---|---|
| **Repository** | the GitHub repository the rig checks out for every run | — |
| **Default branch** | what a run is for when it names no ref | the repository's own |
| **Suite path** | the directory in the repository the rig runs pytest in | `tests` |
| **Families** | the chip families a run takes one board of each; none means the whole bench -- the boards of the families the run chose, which are the ones its bundle carries | none |
| **Supply workflow** | the workflow whose artifact is the bundle | `.github/workflows/hil.yml` |
| **Artifact name** | the Actions artifact that workflow uploads | `hil-artifacts` |
| **Revision key** | the key in the bundle's manifest that holds the commit | `git_sha`, or what the repository's `.alteriom-hil.yaml` declares |
| **Timeout** | how long a run's suite may take | 1800 s |

The rig writes the project as a profile document under
`/var/lib/alteriom-hil/profiles/<name>.yaml`, reads it back at once, and an
upgrade leaves it alone. Edit or remove a project from its page; a project
that shipped with the rig (the Rig example, and painlessMesh, the reference) can be removed and
restored. The same over the API: `GET`/`POST /api/v1/projects`,
`POST /api/v1/projects/inspect`, `POST /api/v1/projects/<name>` to edit,
`.../delete`, `.../restore`, with an admin key.

## 3. The bundle your CI builds

**The rig does not build firmware.** Your CI does, the way it already does,
and the rig flashes exactly that, so it can say afterwards precisely what it
flashed. A bundle is a directory:

```
hil-artifacts/
  manifest.json
  esp32/flash-image.bin        (+ bootloader.bin, partitions.bin, boot_app0.bin, firmware.bin)
  esp32-c3/flash-image.bin     …
```

`manifest.json` is schema 2:

```json
{
  "schema": 2,
  "git_sha": "<the 40-character commit the build resolved to>",
  "targets": {
    "esp32": {
      "chip": "esp32",
      "board": "esp32dev",
      "image": "esp32/flash-image.bin",
      "flash_offset": "0x0",
      "sha256": "<digest of the image>",
      "segments": {"bootloader.bin": "0x1000", "partitions.bin": "0x8000", "boot_app0.bin": "0xe000", "firmware.bin": "0x10000"},
      "files": {"bootloader.bin": {"sha256": "…"}, "partitions.bin": {"sha256": "…"}, "boot_app0.bin": {"sha256": "…"}, "firmware.bin": {"sha256": "…"}}
    }
  }
}
```

- The **revision key** (`git_sha` unless you set another) holds the commit.
  That is what a run is named by, what a bundle is reused by, and what the
  dashboard links. A bundle whose manifest holds the commit under a key the
  project does not name is refused, and the refusal says which key does.
- **`image`** is one merged image per family, flashed whole at
  `flash_offset`. `segments` and `files` are optional; when present the rig
  checks each component sits at its stated offset inside the merged image.
- The rig re-hashes every image and every component before it flashes. A
  flash is the one step that cannot be undone by retrying, and a bundle
  corrupted in transit would otherwise be diagnosed as a firmware bug on
  hardware.

The example's `scripts/build_bundle.py` builds this with PlatformIO and
`esptool merge-bin`: one `pio run -e <family>` per family, the merged image
from the bootloader, partition table, OTA selector and application at their
offsets (the ESP8266 is one image at `0x0`), and the manifest. It is about a
hundred lines and it is yours to change.

## 4. The workflow

```yaml
# .github/workflows/hil.yml
name: HIL
on:
  push:
    branches: [main]
  pull_request:
  workflow_dispatch:
jobs:
  bundle:
    runs-on: ubuntu-latest
    steps:
      - uses: actions/checkout@v4
        with: {fetch-depth: 0}
      - uses: actions/setup-python@v5
        with: {python-version: "3.12"}
      - run: python -m pip install platformio esptool
      - run: python scripts/build_bundle.py --out hil-artifacts
      - uses: actions/upload-artifact@v4
        with:
          name: hil-artifacts        # the project's artifact name on the rig
          path: hil-artifacts        # the bundle directory's contents
          if-no-files-found: error
```

That is all a rig on your LAN needs: **Get firmware from GitHub** on the
project's page takes the newest `hil-artifacts` uploaded by a run of this
workflow, unpacks it, checks it, and holds it for runs. A run of any other
workflow is not taken, on purpose.

A CI that can reach the rig may hand the bundle over instead, in the same
job, with a key of role `user` or `admin` kept as a secret:

```yaml
      - name: Hand the bundle to the rig
        if: github.event_name != 'pull_request'
        env:
          RIG_URL: ${{ secrets.RIG_URL }}
          RIG_KEY: ${{ secrets.RIG_KEY }}
        run: |
          tar -czf bundle.tar.gz hil-artifacts
          curl -fsS -X POST -H "Authorization: Bearer $RIG_KEY" \
            --data-binary @bundle.tar.gz \
            "$RIG_URL/api/v1/artifacts?profile=esp32-rig-example&repo=https://github.com/$GITHUB_REPOSITORY&workflow=.github/workflows/hil.yml&run_id=$GITHUB_RUN_ID&run_url=$GITHUB_SERVER_URL/$GITHUB_REPOSITORY/actions/runs/$GITHUB_RUN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"
```

The rig checks the origin against the project's supply block, the commit
against the manifest, and the checksums; a bundle it already holds for that
commit is reused rather than stored twice.

## 5. The suite

Pytest, in the suite path, with the rig's fixtures available through the
`alteriom_hil` pytest plugin the rig installs. The one you want is `bank`: a
dictionary of board id to a **board client**, one per board the run was
given, each already checked responsive (a silent board is reset once and
named if it stays silent).

```python
# tests/test_it_answers.py
import pytest

pytestmark = pytest.mark.hil_only(reason="real silicon")

def test_every_board_boots_and_says_what_it_is(bank):
    for board_id, board in bank.items():
        info = board.ensure_responsive()
        assert info["family"], f"{board_id} did not say its family"
        assert int(info["freeHeap"]) > 0, f"{board_id} reports no free heap"

def test_the_firmware_adds(bank):
    for board_id, board in bank.items():
        reply = board.send_cmd_awaiting("sum", lambda e: e["evt"] == "sum", "a sum", timeout=5, a=20, b=22)
        assert reply["value"] == 42, board_id
```

The client talks newline-delimited JSON over the board's serial port. Your
firmware answers `{"cmd": "info"}` with `{"evt": "info", "family": …,
"bootId": …, "freeHeap": …}` and announces a start with `{"evt": "boot", …}`;
past that, the commands are yours. The client's methods:

| Method | Does |
|---|---|
| `info(timeout)` | sends `info`, returns the reply |
| `ensure_responsive()` | `info`, resetting the board once over RTS/DTR if it is silent |
| `send_cmd(cmd, **fields)` | writes one command frame |
| `wait_for(predicate, description, timeout)` | the first event matching, keeping the others for later waits |
| `send_cmd_awaiting(cmd, predicate, description, timeout, idempotent=False, **fields)` | send and wait, resending if the firmware said it could not parse the frame |
| `hard_reset()` | RTS/DTR reset, returns the `boot` event |
| `clear_pending()` | forget every event seen so far |

Markers the rig reads: `hil_only(reason)` for a test compile-only CI cannot
exercise (the example runs its suite in its own CI against the rig's
simulator, where those skip); `capability("name")` to say which capability a
test is evidence for, which the report groups by; `failure_class("…")` to
classify a failure. A per-board suite, one test row per board, is the pattern
the health check uses; the example's `conftest.py` shows it in ten lines.

## 6. Run it

**Runs → New run**: the project, the bundle, the boards; **Run**. Or
with a key:

```bash
curl -fsS -X POST -H "Authorization: Bearer $KEY" -H "Content-Type: application/json" \
  https://<rig>/api/v1/suites \
  -d '{"profile": "esp32-rig-example", "ref": "main", "artifact": "<bundle id>"}'
```

`ref` names the commit or branch the suite is checked out at; `artifact`
a bundle the rig holds (or leave it out to take the newest one it holds for
that commit); `targets` a subset of families; `tests` a list of test files or
ids; `keyword` a pytest `-k` expression. The answer is the run's id; its
page, and `GET /api/v1/jobs/<id>`, follow it.

## What a project cannot do

Run on a rig its owner did not add it to. Make the rig build. Reach another
project's bundles or runs. A profile's commands run with the rig's own
privileges: a rig runs projects its owner trusts, which is the point of it
being yours.

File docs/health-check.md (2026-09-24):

# The health check firmware

Every other run on a rig answers "is this project's firmware good on this
hardware". The **Rig Health Check** answers **"is this hardware good"**, and
that is the rig's own question. So the firmware it flashes is the rig's own,
carrying nothing of yours: a red health check is never your regression. It
is an ESP, a cable, a hub port, or the rig's own access point, broker or
uplink.

## Where it lives

The firmware has a repository of its own,
[Alteriom/esp32-hil-firmware](https://github.com/Alteriom/esp32-hil-firmware),
with its own build, its own tests and its own releases. It validates any
hardware the rig supports and changes when a family or a check changes, not
when the rig software does.

The rig **pins** one release of it. `canary/firmware.json` in the rig
repository names the release by version, source digest, tarball digest,
families, the serial commands the firmware answers and the pins it lets an
instrument be wired to. A rig release fetches that tarball, checks it against
the pin, and carries it; `alteriom-hil-admin upgrade` installs and pins it on
the rig. Every rig on a given rig release runs the same health check
firmware, byte for byte, which is what makes one rig's verdict comparable to
another's. Moving the firmware forward is a one-line change to the pin,
reviewed like any other.

## What it checks

Each check runs **once per board**, so a report is a board × check matrix
that separates two kinds of red: a check failing on **every** board is the
rig; a check failing on **one** board is that board.

| Check | Asks |
|---|---|
| **boot** | it started, it is talking, and the part answering (chip, revision, flash size) is the part the registry says is there |
| **serial** | a kilobyte comes back byte for byte: the cable, the hub port and the console driver together |
| **flash** | a value written is read back and erased: NVS on the ESP32 families, a LittleFS file on the ESP8266 |
| **reset** | the board restarts when the rig says so, and comes back as a new boot |
| **radio** | the board sees the rig's access point, joins it, gets an address |
| **uplink** | an HTTP GET from the board reaches the rig's probe and is answered |
| **queue** | a message from the board reaches the rig's MQTT broker |
| **wiring** | every jumper to an instrument carries a level both ways, named per wire when it does not |

Checks that need something the rig does not have (no instrument, no broker)
skip and say so; they do not fail.

## What a red does

- **Red on every board is the rig.** The service pauses its queue itself,
  with the reason, as soon as it records the verdicts: everything queued
  behind that check would otherwise flash boards whose rig cannot join a
  network, and report that as the project's fault. The queue resumes when a
  health check passes, or when you resume it.
- **Red on one board is that board.** It is marked on the Boards page with
  the check that failed. With quarantine turned on in the host configuration,
  a board red on its own checks twice in a row is left out of runs until a
  clean health check, or you, release it.
- **A wiring failure never pauses the rig.** An unplugged instrument fails
  every wired board; that is the instrument, not the network, and runs that
  never touch a wire are not stopped for it.

## The protocol

Newline-delimited JSON both ways, the same framing the rig's board client
already reads. Commands are `{"cmd": "..."}` frames; the firmware answers each
with one event, and announces a start with `{"evt": "boot", ...}`.

| Command | Answer |
|---|---|
| `info` | version, family, source digest, boot id, reset reason, uptime, heap, MAC, and the silicon |
| `echo` `{"text": "..."}` | the text and its length |
| `store_write`, `store_read`, `store_erase` | the operation, whether it succeeded and what was found |
| `wifi_scan` `{"ssid": "..."}` | how many networks, and the named one with RSSI and channel |
| `wifi_join` `{"ssid", "password"}` / `wifi_leave` | joined, address, gateway, RSSI, milliseconds |
| `http_get` `{"url": "http://..."}` | status, bytes, milliseconds |
| `mqtt_publish` `{"host", "port", "topic", "payload"}` | ok, bytes, milliseconds |
| `gpio_mode`, `gpio_write`, `gpio_read`, `gpio_release` `{"pin", ...}` | the operation, the pin, the level; only a wireable pin of the family, never an input-only one driven |
| `reset` | `resetting`, then a fresh `boot` |

A frame the firmware cannot parse is answered `{"evt": "error", "error": "bad
json"}`, a statement that the command did **not** run, which is what makes
the rig's resend safe. The station is never an access point on any family:
a board that brought up an AP would change what every other board on the
rig can see.

The rig's simulator answers the same commands, so the health check suite
runs in the rig's own CI without hardware. A simulated pass is evidence about
the rig's software, never about an ESP: every check carries the `hil_only`
marker for that reason.

## Running it

From the **Boards** page, **Run the Rig Health Check** checks every board;
a board's own page checks that one. A release install runs it once at the
end and is not green until the rig says its own hardware is. On the host:

```bash
sudo alteriom-hil-admin health refresh
```

writes a fresh host health snapshot (disk, throttling, temperature, the
boards seen). The check's report, per board and per check, is on the run's
page like any other run, under the health check's name.

## Its version

Three identities travel in the bundle: the firmware repository's commit it
was built from (the revision of record, what a bundle is reused by), the
digest of its source (what a board reports back over serial, so a report can
say which health check answered), and the version a person reads. The
version's `MAJOR.MINOR` is set by hand in the firmware repository; `PATCH` is
the number of commits that changed the firmware, so it rises by itself when
the firmware does and never when the rig does. The board reports it in its
`boot` and `info` frames, and the suite holds each board to the version the
run flashed.

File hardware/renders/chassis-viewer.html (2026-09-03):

drag orbitscroll zoomshift-drag pan

Alteriom ESP32 HIL rig

# Rig Chassis

Boards upright in a card rack behind the control deck: 330 × 272 mm, eight ports, no printed part longer than 178 mm. Every part here is the real STL at its assembly position.

charcoal PETG, structureorange PETG, lids

## View

Overview Control deck Card rack

## Show

Lids Electronics Base

## Printed parts · click to isolate

printed parts in this assembly

## Plank layout (mm)

x | y | part
0–330 | 0–190 | control deck
16–174 | 16–85 | relay tray
190–300 | 16–86 | hub strap tile, ports to the rear
16–120 | 90–172 | Pi 5 tile
190–306 | 100–142 | PSU cradle, brick on edge
6–166 / 166–326 | 192–272 | rack-4slot × 2
26 + 40·n | — | board slot n = 0…7

Generated by hardware/mounts/generate_chassis.py and generate_mounts.py; assembly from hardware/renders/render_chassis.py. Wiring: docs/relay-power-wiring.md. Measure RELAY_HOLES, BRICK, SOCKET_W/H before printing.

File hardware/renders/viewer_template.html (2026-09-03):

drag orbitscroll zoomshift-drag pan

Alteriom ESP32 HIL rig

# Rig Chassis

Boards upright in a card rack behind the control deck: 330 × 272 mm, eight ports, no printed part longer than 178 mm. Every part here is the real STL at its assembly position.

charcoal PETG, structureorange PETG, lids

## View

Overview Control bay Board station

## Show

Lids Electronics Base

## Printed parts · click to isolate

printed parts in this assembly

## Plank layout (mm)

x | y | part
0–300 | 0–200 | control bay
16–120 | 100–182 | Pi 5 tile
16–126 | 22–92 | hub strap tile
126–284 | 116–185 | relay tray
150–270 | 30–95 | PSU cradle
280–1180 | 16–50 | cable channel
320 + 145·n | 60–130 | board station n = 0…5

Generated by hardware/mounts/generate_chassis.py and generate_mounts.py; assembly from hardware/renders/render_chassis.py. Wiring: docs/relay-power-wiring.md. Measure RELAY_HOLES, BRICK, SOCKET_W/H before printing.

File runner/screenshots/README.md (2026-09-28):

# The guide's screenshots

The pictures in `docs/images/` are the real dashboard, taken by a script of a
demo rig. Take them again after a change to `rig/web/`, and commit them with
it, so the guide shows the dashboard as it is.

| File | What it does |
|---|---|
| `demo_rig.py` | Writes a demo rig's state: four boards (made-up names, locally administered MACs), their health check verdicts and chip readings, the host's health, the installed version, and a week of runs with their reports, results and bundles. |
| `demo_after_start.py` | Run once the service is up. A start runs a discovery, which finds no boards on a host without any, and marks any running run interrupted: this puts the demo's board snapshot back and starts one run that stays in progress. |
| `capture.py` | Opens each page in Chromium (Playwright), signed in with the demo's key, and writes one WebP per page. |

Nothing here touches hardware or a real rig's state. Point `capture.py` only
at the demo.

## The recipe

In a Linux container or a throwaway virtualenv, from the repository root:

```bash
python -m pip install -e ./core -e ./rig
export STATE=/tmp/demo-rig
python runner/screenshots/demo_rig.py
cp $STATE/inventory.json $STATE/inventory.demo.json
openssl rand -hex 24 > /tmp/demo-key
ALTERIOM_HIL_STATUS_FILE=$STATE/status.json ALTERIOM_HIL_VERSION_FILE=$STATE/version.json \
  alteriom-hil-service --mode standalone --repo . --state $STATE \
  --registry $STATE/inventory.yaml --token-file /tmp/demo-key \
  --web-root rig/web --bind 127.0.0.1 --port 8090 &
```

Once the service answers `/healthz`, restore the demo and name the rig's place:

```bash
PYTHONPATH=runner/screenshots python runner/screenshots/demo_after_start.py
curl -s -X POST -H "Authorization: Bearer $(cat /tmp/demo-key)" -H "Content-Type: application/json" \
  -d '{"description": "Four boards on a powered hub", "location": "Bench by the window"}' \
  http://127.0.0.1:8090/api/v1/rig/details
```

Then take the pictures:

```bash
python -m pip install playwright pillow && python -m playwright install --with-deps chromium
BASE=http://127.0.0.1:8090 KEY=$(cat /tmp/demo-key) OUT=docs/images python runner/screenshots/capture.py
```

The rig's name in the pictures is the host's name; run it in a container with
`--hostname bench-01` to match the ones committed. `DEMO_VERSION` sets the
version the demo says it runs.

## Notes

- **The page allows no eval.** Its content security policy blocks the script
  Playwright's waits evaluate, so the capture opens pages with CSP bypassed.
  The page served is the same page a person gets.
- **The console bar is hidden** in the pictures: it is fixed to the window and
  in a still it only covers the page.
- **Times are relative to now.** The demo's runs are written hours and days
  before the moment it runs, so "3h ago" stays true whenever it is taken.

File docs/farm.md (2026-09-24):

# Connecting to a farm

A rig is complete on its own. Connecting it to a farm is a choice you make in
Settings, and one you can unmake.

## What a farm is

A farm is a portal that several rigs report to: one place with a page per
rig, the same page the rig shows on its own dashboard, and a queue it can
hand runs from. The rig software's own farm is the one it shows on its
overview out of the box, where you can see rigs of the same kind and how
they are doing. Nothing there is yours until you connect; `farm.public_url`
in the host configuration points the overview at another farm, or `off`
shows none.

## What connecting does

- **The farm gets this rig's page.** Its name, description and location as
  you wrote them in Settings → Rig; its boards and their health; its runs.
  The rig view is one JSON document (`GET /api/v1/view` on the rig, the same
  shape on the portal per rig), so the farm's page and the rig's own agree
  by construction.
- **The farm can hand it runs.** The rig's agent asks the portal for work,
  runs it on the boards, and reports back. A rig connected to a farm still
  runs its own projects from its own dashboard.
- **The farm can hand it releases.** A portal names the rig release its
  rigs run, and a connected rig installs it through the same path
  `alteriom-hil-admin upgrade` uses, pinned firmware included.
- **The farm does not build your firmware either**, and it does not run
  projects the rig's owner did not add: a rig runs its own projects and no
  other.

## How to connect

On the farm, **Rigs → Add rig** names the rig and gives one command to
paste on the rig's host. Its token works once, for an hour:

```bash
curl -fsSL https://<your-farm>/api/v1/join.sh | bash -s -- --portal https://<your-farm> --token afj_…
```

Run it as the user the rig runs as, sudo-capable, not root. It installs what
a rig needs from apt, trades the token for this rig's node key (kept in
`/etc/alteriom-hil/node-key`, readable by root and the rig's group), takes the
release the farm's rigs run, checks it against the digest the farm gave, and
installs the host as a node of that farm. The rig then says hello and appears
on the farm's **Rigs** page. Stopped halfway, it is re-run the same way: the
key it was given is kept, so the spent token is not needed again.

On a rig that is already installed, the same is done from **Settings → Rig
→ Connection to a farm**, or on the host:

```bash
sudo alteriom-hil-admin config join --portal https://<your-farm> --token afj_…
```

## What the farm sees, and who else does

A rig's visibility on the farm is the rig owner's setting: **private** (the
owner and the farm's admins), **shared** (signed-in users of the farm), or
**public** (the farm's public page shows the rig, its board families, its
health word and its run counts; never a repository, a commit, a test name, a
log or an artifact of a private project). Set it from the rig's page on the
farm, or `POST /api/v1/rigs/<name>/visibility` with the rig owner's key.

## Disconnecting

**Settings → Rig → Connection to a farm → Disconnect**, or on the host set
`farm.mode: standalone` and restart the service. The rig keeps its projects,
its runs and its boards; the farm keeps the history the rig reported while it
was connected, under the rig's name, until the farm's admin deletes the rig
there. Deleting a rig on the farm revokes its key; the host stops reporting
until it joins again.

## Modes, for the record

`farm.mode` in the host configuration:

| Mode | Meaning |
|---|---|
| `standalone` | the queue, the dashboard and the boards in this one service, as a rig begins |
| `node` | the rig works for a portal: runs and releases come from there; the dashboard is still the rig's own |
| `attached` | `standalone` with the node agent beside it, taking portal runs on the same boards; an accepted alias kept for one more release |

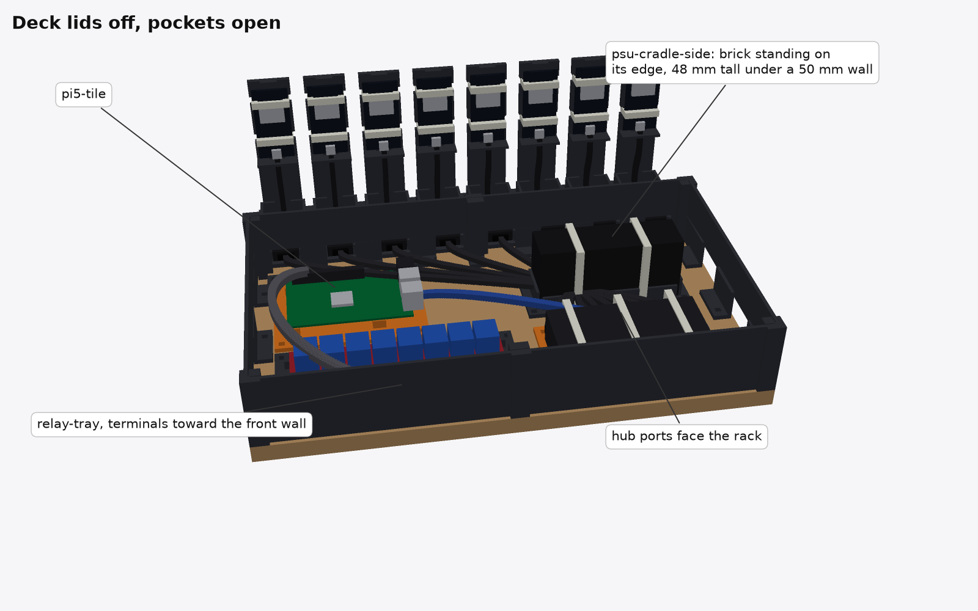
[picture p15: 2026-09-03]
hardware/renders/chassis-deck.png

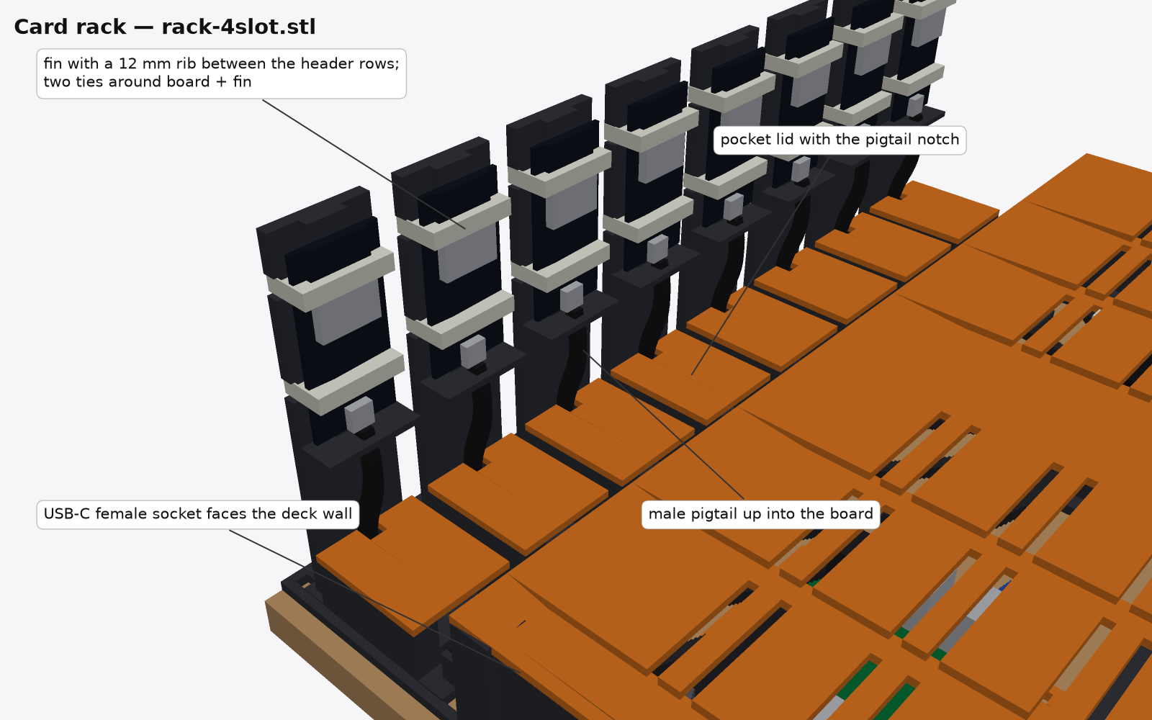
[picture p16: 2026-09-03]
hardware/renders/chassis-rack.png

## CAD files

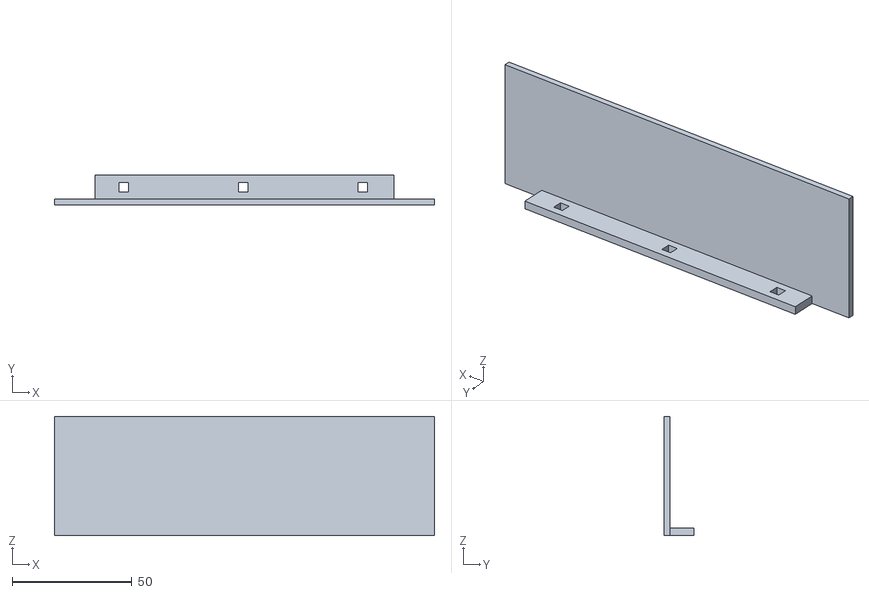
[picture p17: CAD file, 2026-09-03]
hardware/mounts/stl/deck-wall-long.stl
159.0 x 12.4 x 50.0

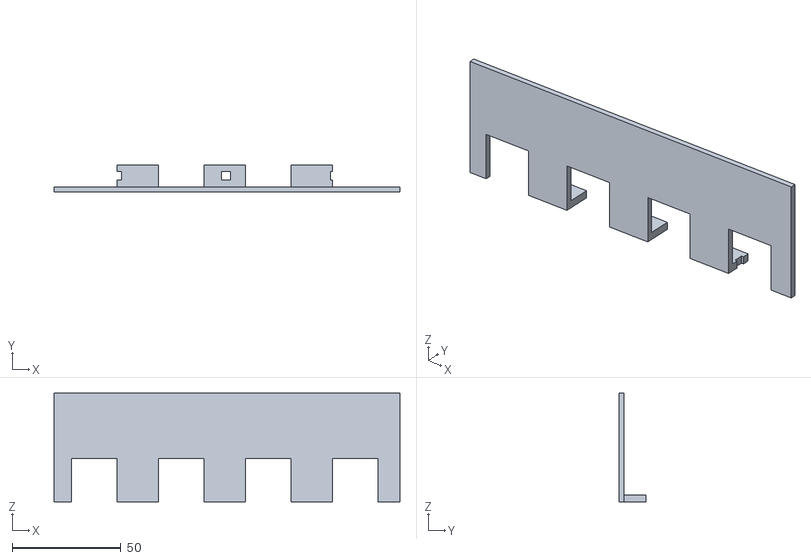
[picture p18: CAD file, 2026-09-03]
hardware/mounts/stl/deck-wall-rear.stl
159.0 x 12.4 x 50.0

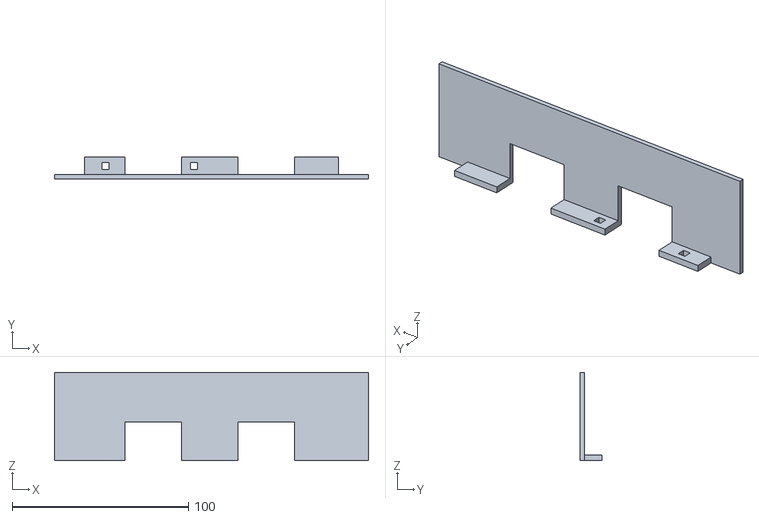
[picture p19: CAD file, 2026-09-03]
hardware/mounts/stl/deck-wall-end.stl
178.0 x 12.4 x 50.0

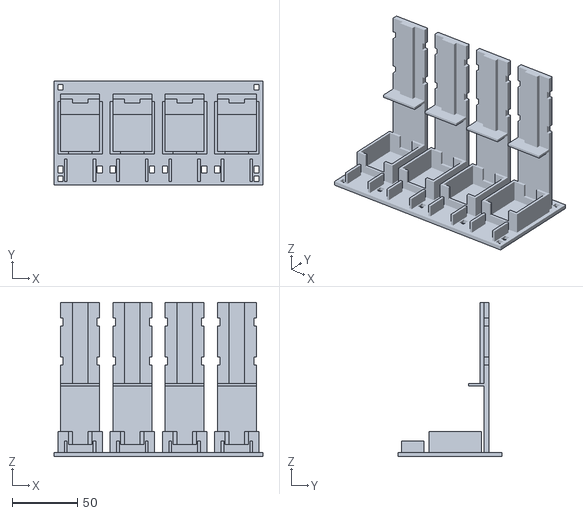
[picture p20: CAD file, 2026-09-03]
hardware/mounts/stl/rack-4slot.stl
160.0 x 80.0 x 118.2

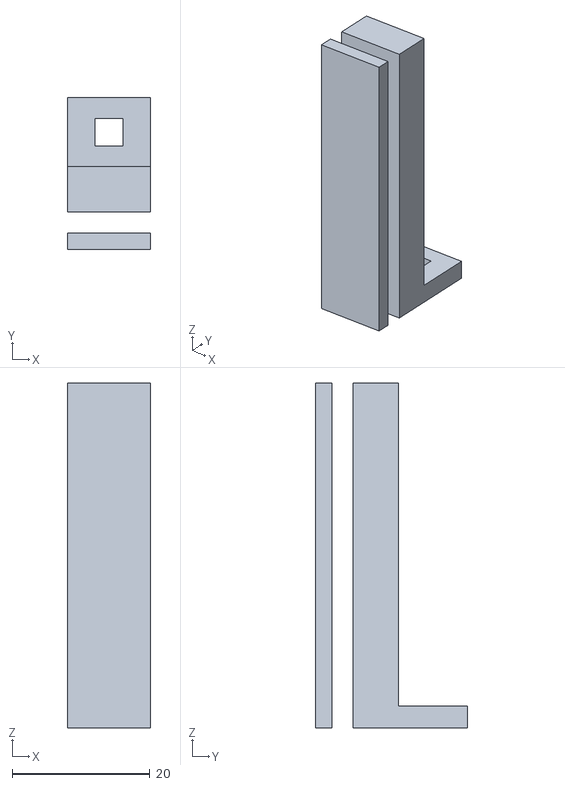
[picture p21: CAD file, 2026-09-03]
hardware/mounts/stl/bay-splice-post.stl
12.0 x 22.0 x 50.0

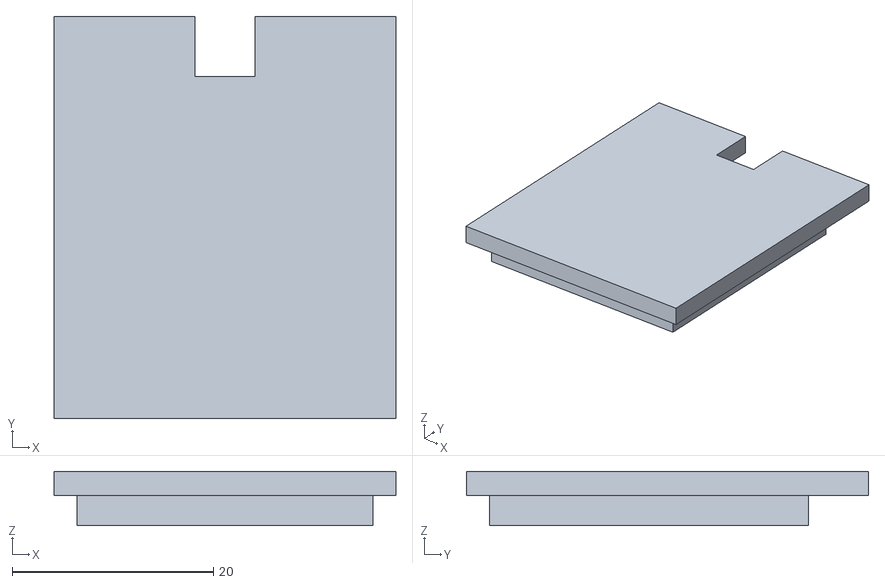
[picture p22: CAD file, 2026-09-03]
hardware/mounts/stl/rack-pocket-lid.stl
34.0 x 40.0 x 5.40

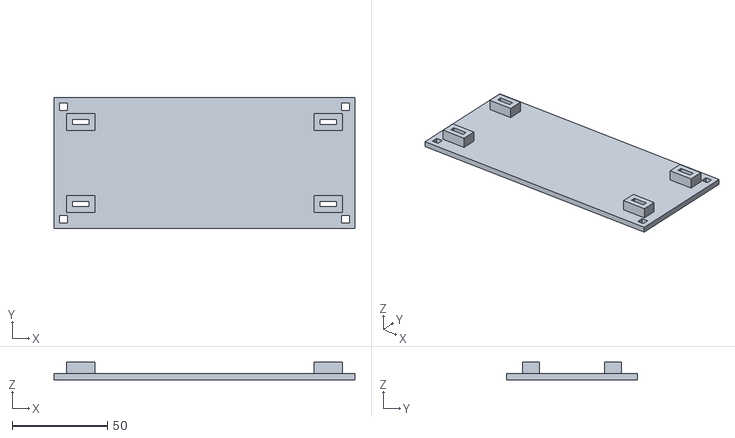
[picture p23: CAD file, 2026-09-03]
hardware/mounts/stl/relay-tray.stl
158.0 x 69.0 x 9.20

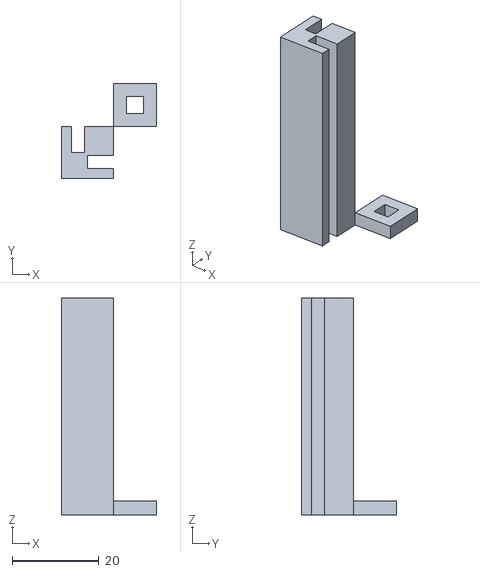
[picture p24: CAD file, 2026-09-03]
hardware/mounts/stl/bay-corner-post.stl
22.0 x 22.0 x 50.0

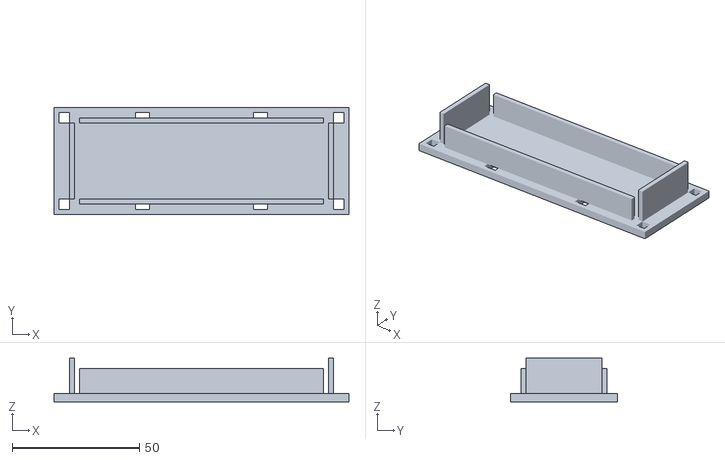
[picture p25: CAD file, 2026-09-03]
hardware/mounts/stl/psu-cradle-side.stl
116.0 x 42.0 x 17.2

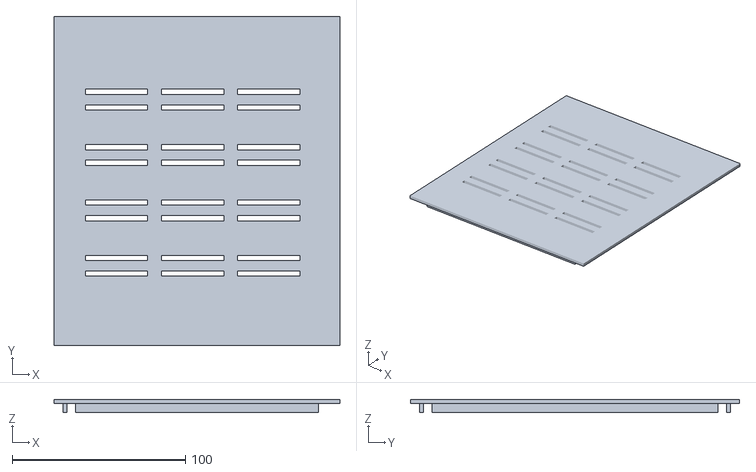
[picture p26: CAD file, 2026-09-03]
hardware/mounts/stl/deck-lid.stl
165.0 x 190.0 x 7.40

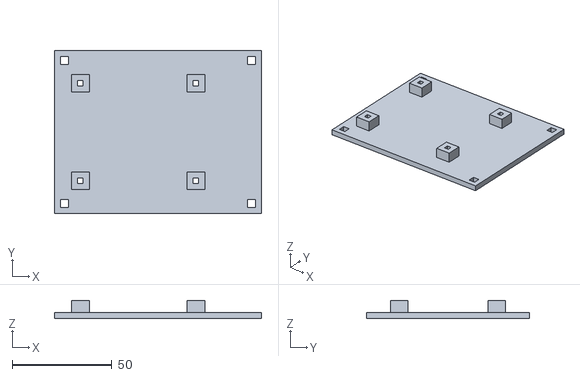
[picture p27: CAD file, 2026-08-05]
hardware/mounts/stl/pi5-tile.stl
104.0 x 82.0 x 9.20

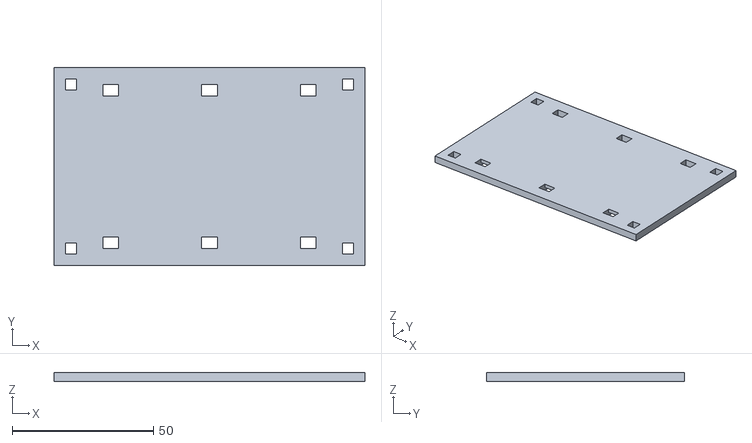
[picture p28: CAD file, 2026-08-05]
hardware/mounts/stl/hub-strap-tile.stl
110.0 x 70.0 x 3.20

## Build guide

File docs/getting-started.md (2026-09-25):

# Getting started

From a box of parts to the first green health check, in about an hour once
the parts are on hand. Everything here is the standalone rig on your bench;
connecting it to a farm is [a separate step](farm.md) you take later, or
never.

## 1. What you need

- A Linux host. A Raspberry Pi 4 or 5 with 2 GB or more is what this was
  built on; any small Debian or Ubuntu box with USB works. Wired Ethernet.
- A **powered** USB hub with its own supply of 4 A or more. Boards draw more
  than a Pi's ports give, and the first symptom of a starved hub is a board
  that "flakes" in ways no firmware explains.
- Two or more ESP32-family dev boards: esp32, esp32-c3, esp32-c5, esp32-c6,
  esp32-s3 or esp8266, in any mix. [Hardware](hardware.md) says which boards
  and cables, and why.

## 2. Install the rig software

On the host, as a user with `sudo`. Pick the release you are installing on
the [releases page](https://github.com/Alteriom/esp32-rig/releases); the
commands below say `1.0.179`.

```bash
sudo apt-get install -y python3-venv git curl
git clone https://github.com/Alteriom/esp32-rig ~/esp32-rig
cd ~/esp32-rig && git checkout v1.0.179
rig/setup-runner.sh              # a virtualenv, the packages, esptool, udev rules, group memberships
rig/install-health-service.sh    # the service, its units, the host configuration, the API key
rig/verify-rig.sh                # what is missing, and what to do about it
```

`verify-rig.sh` says what is missing and what to do about it. The last line
you want ends in `rig is ready`, or, before any board is plugged in, `rig is
set up, with no boards registered yet`.

Then the release's health check firmware and dashboard, checked against the
release's checksums and pinned:

```bash
mkdir -p ~/esp32-rig-release/1.0.179 && cd ~/esp32-rig-release/1.0.179
base=https://github.com/Alteriom/esp32-rig/releases/download/v1.0.179
for f in release.json SHA256SUMS alteriom_hil_core-1.0.179-py3-none-any.whl alteriom_hil-1.0.179-py3-none-any.whl alteriom-hil-dashboard-1.0.179.tar.gz alteriom-hil-canary-1.0.7.tar.gz; do curl -fsSLO "$base/$f"; done
sha256sum -c SHA256SUMS
~/.local/share/alteriom-hil/venv/bin/alteriom-hil-admin upgrade --from .
```

!!! note "A checkout and a release"
    The checkout supplies what a package cannot: the installer, the units,
    the udev rules, the profiles. The release supplies what must be the
    same on every rig: the wheels, the dashboard bundle and the pinned
    health check firmware. Later releases are installed with `upgrade`
    alone. [Bring-up](bringup.md) has the long form, including hardening
    the host and the rig's own test network.

## 3. Open the dashboard

The dashboard listens on the host, port 8090. From the host itself:

```bash
xdg-open http://127.0.0.1:8090 2>/dev/null || echo "open http://127.0.0.1:8090"
```

From another machine on your LAN, put it behind the rig's own reverse proxy
once (it allows your LAN and nothing else):

```bash
sudo ~/esp32-rig/rig/install-dashboard-proxy.sh --lan --network 192.168.1.0/24
```

and open `http://<the rig's address>/`. Sign in with the rig's key:

```bash
sudo cat /etc/alteriom-hil/api-token
```

The key stays in that browser tab. The dashboard opens on the rig's own
page: its boards, its health, its runs. [The dashboard](dashboard.md) walks
through every page.

## 4. Plug the boards in and run the health check

Plug the boards into the hub. On the dashboard's **Boards** page they appear
within a minute, named by family and the last four characters of their MAC
(`esp32-c3-1b30`). The service registers them itself; nothing to type.

Press **Run the Rig Health Check**. The rig flashes every board with its own
small firmware and asks each one whether it boots, whether its serial path
is clean, whether its flash keeps a value, whether it can be reset, whether
it sees the rig's network. A few minutes later every board reads **healthy**
on the Boards page, or says exactly what failed.

!!! tip "A red health check is a hardware or a cable problem"
    The health check firmware depends on nothing of yours. If a board fails
    it, look at the board, the cable and the hub's supply, in that order —
    [Troubleshooting](troubleshooting.md) has the usual suspects.

## 5. Connect GitHub and add your project

A project is a GitHub repository the rig checks out and whose CI builds the
firmware the rig flashes; the rig needs a token to do either. Make a
fine-grained token with **Contents: read** and **Actions: read** on the
repositories you will test, and give it to the rig — on the dashboard under
**Settings → Rig → GitHub**, or on the host:

```bash
sudo alteriom-hil-admin github set
```

Then **Settings → Projects → Add project**, paste the repository's URL and
press **Look it up**. The rig reads the repository and fills the form in;
check it and add. [Projects and your CI](projects.md) explains what the rig
found, what it guessed, and what your CI has to produce — and points at the
example project you can copy.

## 6. Run

**Runs → New run**: choose the project, the bundle to flash (fetched from
GitHub with **Get firmware from GitHub** on the project's page, or handed over
by your CI), and press run. The run's page follows the stages live and keeps
what it left: logs, serial captures, results, a report.

That is the rig. What follows in this guide is detail: the
[hardware](hardware.md) and [bring-up](bringup.md) in depth, the
[health check firmware](health-check.md), [connecting to a farm](farm.md),
the [API](api.md).

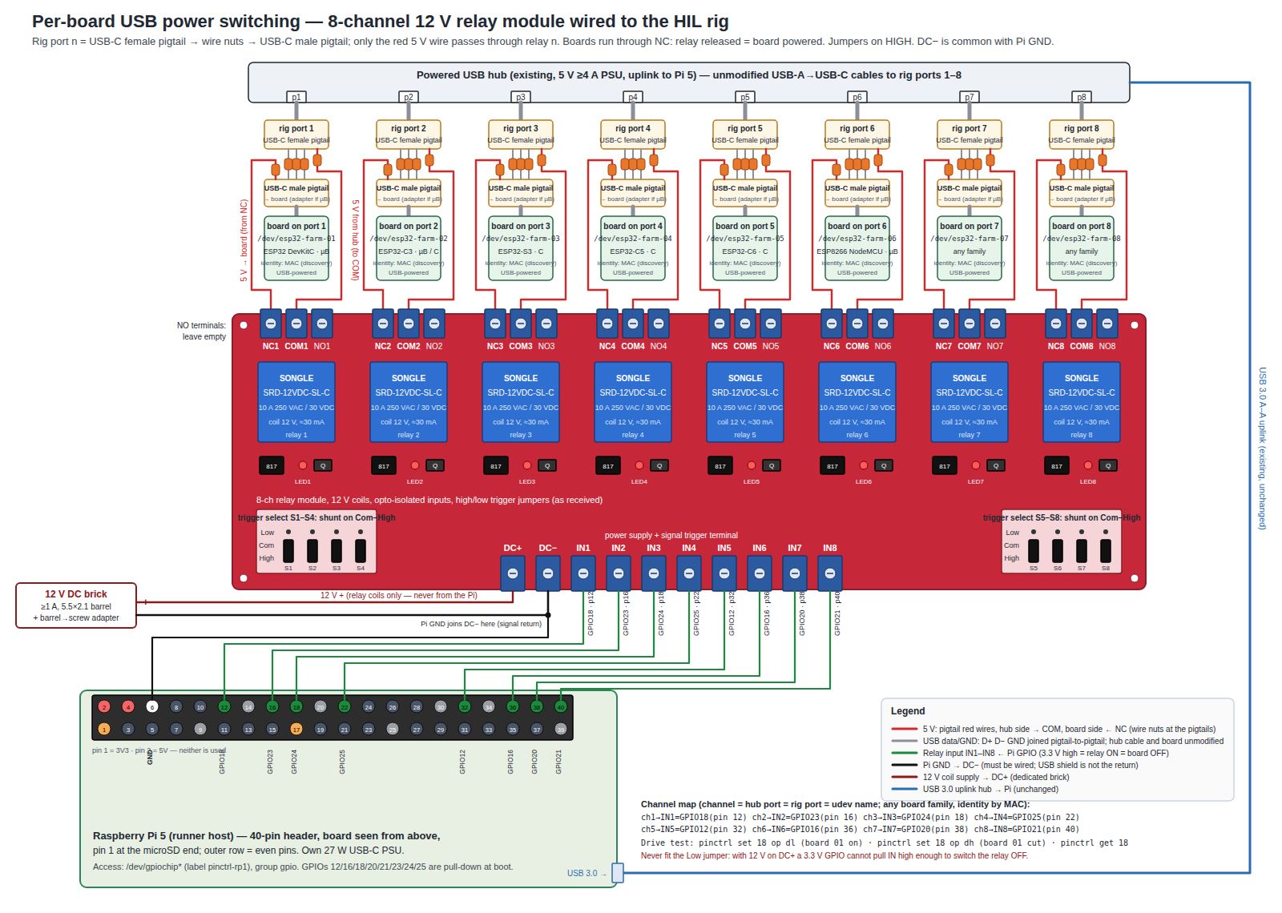
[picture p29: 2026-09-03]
hardware/renders/relay-wiring.png

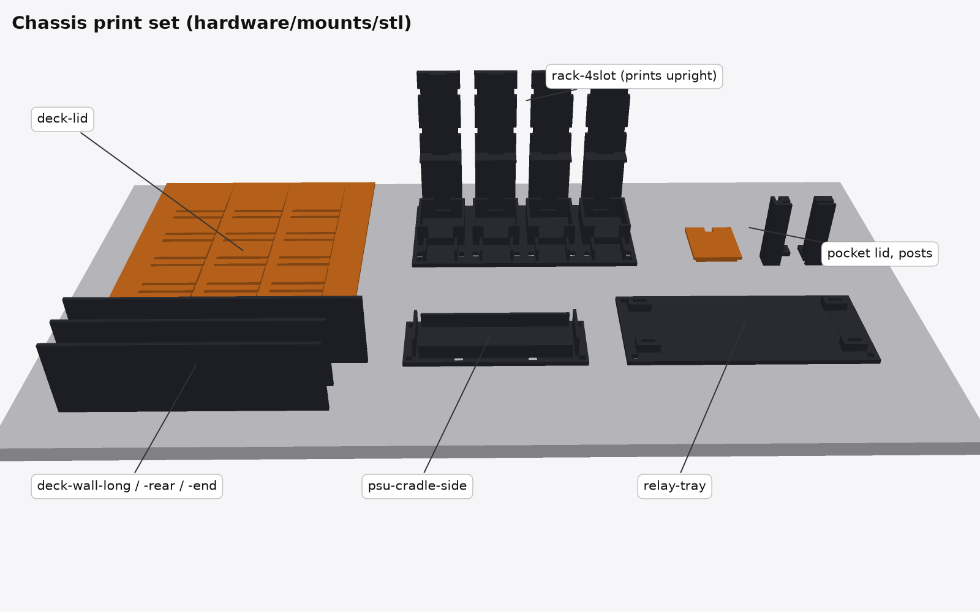
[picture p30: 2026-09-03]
hardware/renders/chassis-printset.png

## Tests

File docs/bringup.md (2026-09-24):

# Bring-up

The order to do things in, on a fresh host, so nothing has to be undone. About
an hour once the parts are on hand. [Getting started](getting-started.md) is
the short form of this page; here is the why, and the steps a fussier host
needs.

## 1. The host, and your key

Flash Raspberry Pi OS Lite (64-bit) or a minimal Debian or Ubuntu; enable
SSH; give the host a DHCP reservation or a static address. Create the user
the rig will run as, sudo-capable, not root. Install your SSH key from the
workstation you will administer the rig from, **before anything else**:

```bash
ssh-copy-id <user>@<rig-address>
ssh -o PasswordAuthentication=no <user>@<rig-address> true
```

From Windows PowerShell, which has no `ssh-copy-id`:

```powershell
type $env:USERPROFILE\.ssh\id_ed25519.pub | ssh <user>@<rig-address> "mkdir -p ~/.ssh && chmod 700 ~/.ssh && tr -d '\r' >> ~/.ssh/authorized_keys && chmod 600 ~/.ssh/authorized_keys"
```

The hardening step turns password logins off, and a rig is usually the
machine nobody has a screen and keyboard for. `harden-pi.sh` refuses to run
until a key is installed, for that reason.

## 2. Plug the boards in

Into the powered hub, in port order if you like labels. Nothing below needs
them unplugged again. Native-USB families through the socket labelled
**USB**, not **UART** ([Hardware](hardware.md)).

## 3. Install the rig

```bash
git clone https://github.com/Alteriom/esp32-rig ~/esp32-rig
cd ~/esp32-rig
git checkout v1.0.169            # the release you are installing; see the releases page
rig/setup-runner.sh              # a virtualenv, the packages, esptool, udev rules, group memberships
rig/install-health-service.sh    # the service, its units, the host configuration, the API key
rig/verify-rig.sh                # what is missing, and what to do about it
```

`setup-runner.sh` makes an isolated virtual environment at
`~/.local/share/alteriom-hil/venv` (Debian's system Python is not touched),
installs the rig's two packages from the checkout, and adds the rig's user
to `dialout` (serial ports) and `video` (the Pi's throttling and temperature
readings). Re-running it is safe. Log out and in once for the new group
memberships.

`install-health-service.sh` writes the systemd units (the service, the health
timer, the nightly backup), the host configuration at
`/etc/alteriom-hil/config.yaml`, the API key at `/etc/alteriom-hil/api-token`,
and starts the service. Nothing of the service is copied out of the venv:
the launcher, the agent, the health check and the admin CLI run by name from
it.

Then the release's firmware and dashboard bundle, checked against the
release's own checksums and pinned:

```bash
mkdir -p ~/esp32-rig-release/1.0.169 && cd ~/esp32-rig-release/1.0.169
base=https://github.com/Alteriom/esp32-rig/releases/download/v1.0.169
for f in release.json SHA256SUMS alteriom_hil_core-1.0.169-py3-none-any.whl alteriom_hil-1.0.169-py3-none-any.whl alteriom-hil-dashboard-1.0.169.tar.gz alteriom-hil-canary-1.0.7.tar.gz; do curl -fsSLO "$base/$f"; done
sha256sum -c SHA256SUMS
~/.local/share/alteriom-hil/venv/bin/alteriom-hil-admin upgrade --from .
```

`upgrade` checks every file against `release.json` and installs nothing if
one disagrees; it installs the wheels, unpacks the dashboard, imports the
health check firmware into the rig's artifact store and pins it. The
firmware's file name is in `release.json` under `firmware.name`.

!!! note "Why both a checkout and a release"
    The checkout supplies what a package cannot: the installer, the units,
    the udev rules, the profiles. The release supplies what must be the
    same on every rig: the wheels, the dashboard bundle and the pinned
    health check firmware. A later release is installed with `upgrade`
    alone, from a directory you downloaded or from the farm the rig is
    connected to.

## 4. Harden the host

Once the key-only login from step 1 works:

```bash
cd ~/esp32-rig/rig
HIL_LAN_CIDR=192.168.1.0/24 HIL_SSH_USER="$USER" ./harden-pi.sh
```

Limits SSH to your LAN, disables password and root SSH logins, enables
unattended security updates, selects headless boot, and disables desktop,
discovery, printing, Bluetooth and RPC services. Keep the original session
open until a second key-only login succeeds.

## 5. Let the boards be found

The service discovers boards when it starts and when you press
**Rediscover** on the Boards page, and registers what it finds
(`inventory.auto_register`, on by default). A board is named by its family
and the last four characters of its MAC. Nothing to type.

`udevadm info -a -n /dev/ttyACM0 | grep KERNELS` gives each port's USB path
if you want stable `/dev/esp32-farm-*` names in the udev rules as well; the
rig does not need them, since it finds a board by its MAC on whichever port
it is.

## 6. The rig's own network

The radio checks need an access point the boards can see, and the uplink and
queue checks need a probe and a broker on the host. Both are one script each,
run once:

```bash
sudo ~/esp32-rig/rig/setup-gateway-network.sh    # hostapd on the host's radio; the probe service
sudo ~/esp32-rig/rig/setup-mqtt-broker.sh        # mosquitto, local only
```

They fill in the `gateway` and `mqtt` sections of the host configuration.
Without them, the radio, uplink and queue checks skip and say so; the rest
of the health check runs.

## 7. Reach the dashboard

From the host, `http://127.0.0.1:8090`. From your LAN, the rig's own reverse
proxy, allowing your LAN and nothing else:

```bash
sudo ~/esp32-rig/rig/install-dashboard-proxy.sh --lan --network 192.168.1.0/24
```

For a rig with a name on the Internet, `--host rig.example.org`, then once
DNS and ports 80/443 reach it, `--host rig.example.org --issue --email you@example.org`
for a Let's Encrypt certificate. Sign in with the rig's key:

```bash
sudo cat /etc/alteriom-hil/api-token
```

## 8. First health check

**Boards → Run the Rig Health Check.** Every board healthy, or the check that
was not and why. Then [connect GitHub and add a project](projects.md).

## Later: upgrading

From the dashboard: **Settings → Rig → Software** says what is installed and
what is newer; **Check for updates** asks now; **Install** fetches the
release, checks every file against the release's own document, and hands it
to the rig's update unit, which installs the wheels, the dashboard and the
pinned health check firmware, moves the checkout to the release's tag,
re-runs the installer and restarts the service. **Install updates
automatically** does the same on its own when the rig is idle, and is off
until you turn it on. What happened is in
`/var/lib/alteriom-hil/update/update.log`.

By hand, the same thing:

```bash
alteriom-hil-admin upgrade --from <directory with the release's files>    # a release you downloaded
alteriom-hil-admin upgrade                                                # the one your farm names, if connected
```

`--no-firmware` leaves a health check firmware you pinned yourself alone.

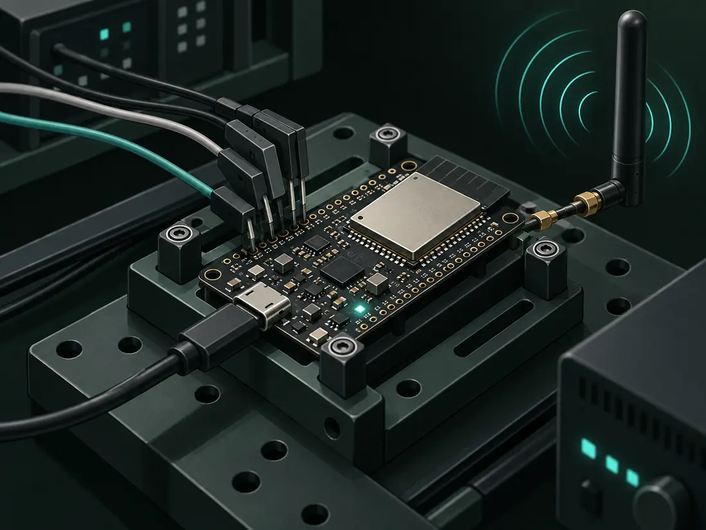
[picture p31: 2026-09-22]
rig/web/brand/board-under-test.webp

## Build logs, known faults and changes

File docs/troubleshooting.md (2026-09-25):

# Troubleshooting

In the order things usually go wrong. Each entry says what you see, what it
is, and what to do. Start with `rig/verify-rig.sh`: it checks every
precondition the rig depends on and names the one that is broken.

## A board never appears on the Boards page

- **The cable.** Charge-only cables look identical and carry no data. Swap it
  for one you know carries data.
- **The wrong socket.** On a C3, C5, C6 or S3 devkit, cable the socket
  labelled **USB**, not **UART**. On the UART socket the board flashes but is
  silent on the port the rig watches. `alteriom-hil-admin boards discover`
  says when a native-USB family is reached through a bridge.
- **Permissions.** The rig's user needs the `dialout` group for serial ports
  and `video` for the Pi's throttling and temperature readings. The installer
  adds both; log out and in, or reboot, for a new membership to apply.
- **Discovery has not run.** The service discovers when it starts and when
  you press **Rediscover** on the Boards page. A board plugged in later shows
  up on the next discovery. Registration is automatic unless
  `inventory.auto_register` was turned off in the host configuration.

## A board appears but every check on it is red

- **Power.** The hub must have its own supply of 4 A or more. A board on a
  starved hub boots, browns out under the radio, and fails in ways no
  firmware explains. The host's own health snapshot reports the Pi's
  throttling too.
- **The cable, again.** The serial check sends a kilobyte and expects it back
  byte for byte; a marginal cable drops bytes only on long lines, which is why
  the check uses one.
- **The board.** A part whose flash has worn out passes boot and serial and
  fails flash. Replace it; that is what the check is for.

## Every board is red on the same check

That is the rig, not the boards, and the queue has paused itself with the
reason. Radio: the rig's access point is down (`sudo systemctl status
hostapd`) or its password file changed. Uplink: the probe service on the host
is not running. Queue: the broker is not running or not enabled in the host
configuration. Fix it and run the health check again; a pass resumes the
queue, or resume it yourself from the Runs page.

## "board map not found" from verify-rig.sh

A legacy check. Boards are registered by the service now; the warning is
about a YAML file older rigs were configured with. If the Boards page lists
your boards, ignore it.

## Settings → Projects offers no Add project

The rig has no GitHub token. Add one under **Settings → Rig → GitHub**, or
`sudo alteriom-hil-admin github set` on the host, then
`alteriom-hil-admin github check` to see who the token is and that GitHub
accepts it. A fine-grained token needs **Contents: read** and **Actions:
read** on the repositories the rig will test.

## Adding a project is refused

The message is GitHub's answer, and for a fine-grained token it names the
private repositories the token was given: the new one is not among them (not selected
when the token was made, or an organisation that has not approved it).
Add it to the token's *Repository access* on GitHub, press **Check again**
on Settings → Rig → GitHub, and add the project again. Or the URL is not a
GitHub repository.

## Get firmware from GitHub is refused with a 403

The token sees the repository but may not list its Actions artifacts: it
lacks **Actions: read** there. The GitHub card's per-project table says so
("fetches its bundles: no").

## The Overview says the token expires soon

Fine-grained tokens expire. Make a new one on GitHub with the same
repositories and permissions and paste it under Settings → Rig → GitHub
(**Replace**); nothing else changes.

## Get firmware from GitHub finds nothing

The rig looks for the newest artifact named `hil-artifacts` (or what the
project's supply block names) uploaded by a run of the project's supply
workflow (`.github/workflows/hil.yml` by default). Check the workflow ran on
the branch you expect, that it uploaded the artifact under that name, that
the artifact has not expired, and that the token has **Actions: read**. A
run of a different workflow is not taken, on purpose.

## A run is refused at submit for want of a bundle

The rig does not build firmware. A run flashes a bundle the rig holds for
the commit, or one you name. Fetch one first from the project's page, or
have your CI hand one over (`POST /api/v1/artifacts`). The message names
the workflow the rig expects the bundle from.

## The bundle is refused

The rig re-hashes every image and every component and checks each
component sits at its stated offset inside the merged image. A refusal
names what disagreed. Most often: the manifest's revision key is missing
or not the 40-character commit; a family in the manifest has no image; a
file was rebuilt after the manifest was written. When the manifest holds
the commit under another key than the project names, the refusal says
which -- change the project's revision key to it (its page, **Change**).

## The dashboard says the key is wrong

The rig's own key is `sudo cat /etc/alteriom-hil/api-token` on the host. Keys
you made with `alteriom-hil-admin keys create` are shown once, at creation.
A key is kept in that browser tab only.

## The host is "unhealthy"

The host health snapshot (every five minutes, and `alteriom-hil-admin health
refresh` on demand) fails the host on: disk above the critical percentage,
the Pi reporting under-voltage or throttling, fewer boards than
`health.minimum_boards`, or the service down. The dashboard's Host page shows
which. Under-voltage on a Pi 5 is almost always a supply that is not the
official 27 W one.

## A board stops answering mid-suite

A board that hard-hangs stays hung: port open, silent, no watchdog. The bank
resets a silent board once, over RTS/DTR, before anything is measured, and
names one that stays dead rather than letting a later test blame the
project. If the same board does this often, it is that board or its port.

## An update failed, or never started

**Settings → Rig → Software** shows the last state and the reason. The
rig's own part is fetching and checking the release; a file that is not
what the release's document says stops it there, with the file named. The
install itself is the update unit's:

```bash
systemctl status alteriom-hil-update.path alteriom-hil-update.service
tail -n 60 /var/lib/alteriom-hil/update/update.log
```

A path unit that is not enabled (a rig installed before updates from the
page) is enabled by re-running `rig/install-health-service.sh` from the
checkout. An install is refused while runs are in progress: it restarts the
service.

## Where the logs are

- **The service:** `journalctl -u alteriom-hil-farm -e`
- **A run:** its page on the dashboard keeps the pipeline log, per-board
  serial captures, the JUnit results and the report; the same files are under
  the run's directory in `/var/lib/alteriom-hil/`.
- **The host health snapshot:** `alteriom-hil-admin status`.

## Reinstalling from scratch

`alteriom-hil-admin backup create` writes the job database, the registries,
the configuration and the pinned bundles (never a secret) to the backup
directory; nightly by default. `backup restore --apply` puts one back. The
GitHub token and the API key are not in a backup: set them again.

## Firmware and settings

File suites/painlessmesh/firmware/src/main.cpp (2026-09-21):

//************************************************************
// painlessMesh HIL agent
//
// Flashed onto every board in the farm for a test run. Joins the test
// mesh and exposes a newline-JSON serial REPL that the pytest suite
// drives (see alteriom_hil.protocol.BoardClient — keep both sides and
// alteriom_hil/sim.py in lockstep).
//
// host -> board commands:
//   {"cmd":"info"}
//   {"cmd":"node_list"}
//   {"cmd":"send_single","dest":123,"msg":"x","ack":true,"ackTimeoutMs":5000}
//   {"cmd":"send_broadcast","msg":"x","ack":true,"ackTimeoutMs":5000,
//    "includeSelf":false}
//   {"cmd":"gateway_start","ssid":"x","password":"y"}
//   {"cmd":"shared_gateway_start","ssid":"x","password":"y"}
//   {"cmd":"gateway_failover_start","ssid":"x","password":"y"}
//   {"cmd":"gateway_status"}
//   {"cmd":"internet_send","tag":"case-1","url":"http://...","payload":""}
//   {"cmd":"mesh_configure","prefix":"run-x","password":"..."}
//   {"cmd":"mesh_start"}       // return a gateway to regular mesh mode
//   {"cmd":"stall","ms":3000}     // stop servicing mesh.update() for ms
//
// board -> host events (one JSON object per line):
//   boot, info, node_list, send_result, recv, ack, connection, stalled,
//   error
//   mesh_log — painlessMesh's own log lines, framed so they cannot splice
//   into a protocol frame; the HAL keeps them in the serial log only
//   capacity_warning — ESP8266 only: below 12 KB free with more than one
//   AP child; the part is specified as a leaf in meshes that size
//************************************************************
#include <painlessMesh.h>

#include <ArduinoJson.h>
#include <MD5Builder.h>

#include "hil_platform.h"

#ifndef HIL_MESH_PREFIX
#define HIL_MESH_PREFIX "AlteriomHILMesh"
#endif
#ifndef HIL_MESH_PASSWORD
#define HIL_MESH_PASSWORD "hil-not-secret"
#endif
#ifndef HIL_MESH_PORT
#define HIL_MESH_PORT 5555
#endif
#ifndef HIL_AGENT_VERSION
#define HIL_AGENT_VERSION "0.1.0"
#endif
#ifndef HIL_ARTIFACT_TARGET
#define HIL_ARTIFACT_TARGET "unknown"
#endif
#ifndef HIL_PAINLESSMESH_REF
#define HIL_PAINLESSMESH_REF "unknown"
#endif
#ifndef HIL_AGENT_SHA
#define HIL_AGENT_SHA "unknown"
#endif
#ifndef HIL_OTA_GENERATION
#define HIL_OTA_GENERATION 1
#endif

constexpr size_t HIL_OTA_PART_SIZE = 1024;
constexpr const char *HIL_OTA_FILE = "/hil-ota.bin";

Scheduler userScheduler;
painlessMesh mesh;

// Every reboot the host asks for is an orderly one: the mesh is stopped
// first, so a bridge announces that it is stepping down and the candidates
// hold their election now rather than a minute after its last status. A
// node that loses power says nothing, and that path stays as slow as the
// status timeout makes it.
void restartAgent() {
  mesh.stop();
  delay(200);
  ESP.restart();
}

uint32_t stallUntil = 0;
uint32_t bootId = 0;
// One line buffer per console: bytes from two ports interleaved into a
// single buffer would splice two commands into nonsense. lastByteMs is
// what lets a frame that lost its newline be reported instead of sitting
// in the buffer until the next command's newline turns both into one
// "bad json" — or, worse, sitting there silently.
struct ConsoleLine {
  String buffer;
  uint32_t lastByteMs = 0;
};
ConsoleLine serialLine;
#if HIL_HAS_SECOND_CONSOLE
ConsoleLine secondLine;
#endif
// Longer than any command but an OTA chunk, which is chunked by the host.
constexpr size_t CONSOLE_LINE_RESERVE = 768;
constexpr uint32_t CONSOLE_LINE_STALE_MS = 500;
RoleStore rolePreferences;
String activeMeshPrefix = HIL_MESH_PREFIX;
String activeMeshPassword = HIL_MESH_PASSWORD;
File otaUploadFile;
File otaSourceFile;
size_t otaExpectedSize = 0;
size_t otaUploadedSize = 0;
size_t otaLastChunkOffset = 0;
size_t otaLastChunkLength = 0;
String otaExpectedMd5;
String otaSourceMd5;
String otaSourceRole;
String otaLastChunkMd5;
std::shared_ptr<Task> otaOfferTask;

void receivedCallback(uint32_t from, String &msg);
void newConnectionCallback(uint32_t nodeId);

// Every console this board exposes, so the rig sees the protocol whichever
// socket is cabled. The native USB CDC is skipped while nothing is attached
// to it: HWCDC blocks for its transmit timeout when no host is listening, and
// paying that on every frame would slow the agent to a crawl on a board wired
// through its UART socket.
// flushNow=false is for diagnostics. flush() blocks until the bytes are out:
// on a real UART that is ~9 ms per frame at 115200, and on HWCDC up to the
// transmit timeout. Paying that on every mesh_log line stalls loop() — and a
// loop that is not running is not reading commands, which is how the C5 came
// to miss a mesh_configure it answers in 60 ms when idle. A reply the host is
// waiting on still flushes; diagnostics leave with the next one.
void consoleWriteLine(const char *frame, bool flushNow = true) {
#if HIL_HAS_SECOND_CONSOLE
  if (Serial) {
    Serial.println(frame);
    if (flushNow) Serial.flush();
  }
  HIL_SECOND_CONSOLE.println(frame);
  if (flushNow) HIL_SECOND_CONSOLE.flush();
#else
  Serial.println(frame);
  if (flushNow) Serial.flush();
#endif
}

void consoleWriteLine(const String &frame, bool flushNow = true) {
  consoleWriteLine(frame.c_str(), flushNow);
}

void consoleFlush() {
#if HIL_HAS_SECOND_CONSOLE
  if (Serial) Serial.flush();
  HIL_SECOND_CONSOLE.flush();
#else
  Serial.flush();
#endif
}

void emitEvent(JsonDocument &doc, bool flushNow = true) {
  // Build one complete frame before writing it. This avoids damaged JSON
  // prefixes on inexpensive USB-UART bridges under concurrent mesh traffic.
  String frame;
  if (!doc.overflowed() && frame.reserve(measureJson(doc) + 1)) {
    serializeJson(doc, frame);
  }
  if (doc.overflowed() || frame.length() <= 2) {
    // Out of memory: the document or its frame could not be allocated. On
    // the rig an ESP8266 printed "{}" in place of an internet_result and the
    // row waited out its timeout for an event the board had already tried to
    // send. Say so from the stack, naming the event where it is readable.
    const char *evt = doc["evt"] | "unknown";
    char line[128];
    snprintf(line, sizeof(line),
             "{\"evt\":\"event_dropped\",\"dropped\":\"%s\",\"reason\":\"out of memory\"}",
             evt);
    consoleWriteLine(line, flushNow);
    return;
  }
  consoleWriteLine(frame, flushNow);
}

void emitError(const char *message) {
  JsonDocument doc;
  doc["evt"] = "error";
  doc["error"] = message;
  emitEvent(doc);
}

#ifdef ESP32
// painlessMesh logs from the Wi-Fi event task as well as from loop().
// Written straight to Serial they splice into a JSON frame byte-for-byte,
// which is why regular nodes used to run at ERROR only — and why a node
// that sat associated-without-an-address for eighty seconds left no trace
// of what its radio was doing. The library hands each line to the sink;
// it is queued under a critical section and framed between protocol
// frames by loop(). The ring is small on purpose: a burst beyond it is
// counted, not paid for in RAM.
constexpr size_t MESH_LOG_LINES = 24;
constexpr size_t MESH_LOG_LINE_MAX = 160;
struct MeshLogRing {
  char lines[MESH_LOG_LINES][MESH_LOG_LINE_MAX];
  uint16_t levels[MESH_LOG_LINES];
  // millis() when the line was produced, not when it is drained: draining is
  // deferred behind commands, so a drain-time stamp would not order these
  // against the protocol events they need to be read alongside.
  uint32_t stamps[MESH_LOG_LINES];
  size_t head = 0;
  size_t count = 0;
  size_t dropped = 0;
  portMUX_TYPE mux = portMUX_INITIALIZER_UNLOCKED;
} meshLog;

void meshLogSink(painlessmesh::logger::LogLevel type, const char *message) {
  portENTER_CRITICAL(&meshLog.mux);
  if (meshLog.count == MESH_LOG_LINES) {
    meshLog.dropped++;
    portEXIT_CRITICAL(&meshLog.mux);
    return;
  }
  size_t slot = (meshLog.head + meshLog.count) % MESH_LOG_LINES;
  strncpy(meshLog.lines[slot], message, MESH_LOG_LINE_MAX - 1);
  meshLog.lines[slot][MESH_LOG_LINE_MAX - 1] = '\0';
  meshLog.levels[slot] = type;
  meshLog.stamps[slot] = millis();
  meshLog.count++;
  portEXIT_CRITICAL(&meshLog.mux);
}

const char *meshLogLevelName(uint16_t type) {
  using namespace painlessmesh::logger;
  switch (type) {
    case ERROR: return "ERROR";
    case STARTUP: return "STARTUP";
    case MESH_STATUS: return "MESH_STATUS";
    case CONNECTION: return "CONNECTION";
    case SYNC: return "SYNC";
    case S_TIME: return "S_TIME";
    case COMMUNICATION: return "COMMUNICATION";
    case GENERAL: return "GENERAL";
    case MSG_TYPES: return "MSG_TYPES";
    case REMOTE: return "REMOTE";
    case APPLICATION: return "APPLICATION";
    case DEBUG: return "DEBUG";
  }
  return "OTHER";
}

// Two lines per pass: a scan logs a dozen at once, and each frame costs a
// flush at 115200 baud that mesh.update() should not wait long for.
void drainMeshLog() {
  for (int n = 0; n < 2; ++n) {
    char line[MESH_LOG_LINE_MAX];
    uint16_t level;
    uint32_t stamp;
    size_t dropped;
    portENTER_CRITICAL(&meshLog.mux);
    if (meshLog.count == 0) {
      portEXIT_CRITICAL(&meshLog.mux);
      return;
    }
    memcpy(line, meshLog.lines[meshLog.head], MESH_LOG_LINE_MAX);
    level = meshLog.levels[meshLog.head];
    stamp = meshLog.stamps[meshLog.head];
    meshLog.head = (meshLog.head + 1) % MESH_LOG_LINES;
    meshLog.count--;
    dropped = meshLog.dropped;
    meshLog.dropped = 0;
    portEXIT_CRITICAL(&meshLog.mux);
    size_t len = strlen(line);
    while (len > 0 && (line[len - 1] == '\n' || line[len - 1] == '\r')) {
      line[--len] = '\0';
    }
    JsonDocument doc;
    doc["evt"] = "mesh_log";
    doc["ms"] = stamp;
    doc["level"] = meshLogLevelName(level);
    doc["line"] = line;
    if (dropped > 0) doc["dropped"] = dropped;
    emitEvent(doc, /*flushNow=*/false);
  }
}
#endif

void handleInfo() {
  JsonDocument doc;
  doc["evt"] = "info";
  doc["nodeId"] = mesh.getNodeId();
  doc["version"] = HIL_AGENT_VERSION;
  doc["target"] = HIL_ARTIFACT_TARGET;
  doc["painlessMeshRef"] = HIL_PAINLESSMESH_REF;
  doc["hilAgentSha"] = HIL_AGENT_SHA;
  doc["bootId"] = bootId;
  doc["freeHeap"] = ESP.getFreeHeap();
  doc["meshPrefix"] = activeMeshPrefix;
  doc["otaGeneration"] = HIL_OTA_GENERATION;
#ifdef PAINLESSMESH_HAS_TCP_LISTENING
  // Whether the mesh listener exists and is in LISTEN. painlessMesh #466
  // crashed a node inside init() on this pointer before it served a
  // connection; #435 had a promoted bridge serving nothing for two minutes
  // with its listener not listening. Reported so the rig can assert it
  // rather than infer it from a peer eventually connecting. Absent on
  // library revisions before the accessor existed.
  doc["listening"] = mesh.tcpListening();
#endif
  emitEvent(doc);
}

void emitOtaEvent(const char *eventName, bool ok = true) {
  JsonDocument doc;
  doc["evt"] = eventName;
  doc["ok"] = ok;
  doc["bytes"] = otaUploadedSize;
  emitEvent(doc);
}

void handleOtaReceiveEnable(JsonDocument &cmd) {
  String role = cmd["role"].as<String>();
  if (role.length() == 0 || role.length() > 31) {
    emitError("ota_receive_enable requires a 1..31 character role");
    return;
  }
  HIL_FS_BEGIN();
  HIL_FS.remove("/ota_fw.json");
  rolePreferences.begin("hil-role", false);
  rolePreferences.putBool("otaReceive", true);
  rolePreferences.putString("otaRole", role);
  rolePreferences.end();
  JsonDocument doc;
  doc["evt"] = "ota_receiver_restarting";
  doc["role"] = role;
  emitEvent(doc);
  consoleFlush();
  restartAgent();
}

void handleOtaUploadBegin(JsonDocument &cmd) {
  size_t size = cmd["size"] | (size_t)0;
  String md5 = cmd["md5"].as<String>();
  String role = cmd["role"].as<String>();
  if (size == 0 || md5.length() != 32 || role.length() == 0 ||
      role.length() > 31) {
    emitError("ota_upload_begin requires size, MD5, and role");
    return;
  }
  if (!HIL_FS_BEGIN()) {
    emitError("unable to mount the filesystem for OTA source");
    return;
  }
  if (otaUploadFile) otaUploadFile.close();
  HIL_FS.remove(HIL_OTA_FILE);
  otaUploadFile = HIL_FS.open(HIL_OTA_FILE, HIL_FILE_WRITE);
  if (!otaUploadFile) {
    emitError("unable to create OTA source file");
    return;
  }
  otaExpectedSize = size;
  otaUploadedSize = 0;
  otaLastChunkOffset = 0;
  otaLastChunkLength = 0;
  otaExpectedMd5 = md5;
  otaSourceRole = role;
  otaLastChunkMd5 = "";
  emitOtaEvent("ota_upload_ready");
}

void handleOtaUploadChunk(JsonDocument &cmd) {
  String encoded = cmd["data"].as<String>();
  size_t offset = cmd["offset"] | (size_t)-1;
  size_t expectedLength = cmd["length"] | (size_t)0;
  String expectedMd5 = cmd["md5"].as<String>();
  if (!otaUploadFile || encoded.length() == 0) {
    emitError("invalid OTA upload chunk or offset");
    return;
  }
  auto decoded = painlessmesh::base64::decode(encoded);
  MD5Builder chunkMd5;
  chunkMd5.begin();
  chunkMd5.add(reinterpret_cast<uint8_t *>(const_cast<char *>(decoded.c_str())),
               decoded.length());
  chunkMd5.calculate();
  if (decoded.length() != expectedLength || expectedMd5.length() != 32 ||
      !chunkMd5.toString().equalsIgnoreCase(expectedMd5)) {
    emitOtaEvent("ota_upload_retry", false);
    return;
  }
  // A USB-UART frame can be damaged after the board has committed the chunk
  // but before the host parses its acknowledgement.  Treat an exact retry of
  // the last committed chunk as idempotent; the final whole-image MD5 remains
  // authoritative and the file is never written twice.
  if (offset == otaLastChunkOffset && expectedLength == otaLastChunkLength &&
      expectedMd5.equalsIgnoreCase(otaLastChunkMd5) &&
      offset + expectedLength == otaUploadedSize) {
    emitOtaEvent("ota_upload_chunk");
    return;
  }
  if (offset != otaUploadedSize) {
    emitError("invalid OTA upload chunk or offset");
    return;
  }
  size_t written = otaUploadFile.write(
      reinterpret_cast<const uint8_t *>(decoded.c_str()), decoded.length());
  if (written != decoded.length()) {
    emitError("OTA source write failed");
    return;
  }
  otaLastChunkOffset = offset;
  otaLastChunkLength = written;
  otaLastChunkMd5 = expectedMd5;
  otaUploadedSize += written;
  emitOtaEvent("ota_upload_chunk");
}

void handleOtaUploadFinish() {
  if (otaUploadFile) otaUploadFile.close();
  if (otaUploadedSize != otaExpectedSize) {
    emitError("OTA source size mismatch");
    return;
  }
  auto source = HIL_FS.open(HIL_OTA_FILE, HIL_FILE_READ);
  if (!source) {
    emitError("unable to verify OTA source file");
    return;
  }
  MD5Builder md5;
  md5.begin();
  md5.addStream(source, source.size());
  md5.calculate();
  source.close();
  otaSourceMd5 = md5.toString();
  if (!otaSourceMd5.equalsIgnoreCase(otaExpectedMd5)) {
    emitError("OTA source MD5 mismatch");
    return;
  }
  emitOtaEvent("ota_upload_verified");
}

void handleOtaOffer() {
  if (otaSourceMd5.length() != 32 || otaUploadedSize != otaExpectedSize) {
    emitError("verified OTA source is required before offer");
    return;
  }
  if (otaSourceFile) otaSourceFile.close();
  otaSourceFile = HIL_FS.open(HIL_OTA_FILE, HIL_FILE_READ);
  if (!otaSourceFile) {
    emitError("unable to open OTA source for mesh transfer");
    return;
  }
  mesh.initOTASend(
      [](painlessmesh::plugin::ota::DataRequest pkg, char *buffer) {
        size_t offset = HIL_OTA_PART_SIZE * pkg.partNo;
        if (offset >= otaSourceFile.size()) return (size_t)0;
        otaSourceFile.seek(offset);
        size_t remaining = otaSourceFile.size() - offset;
        return otaSourceFile.readBytes(
            buffer, remaining < HIL_OTA_PART_SIZE ? remaining : HIL_OTA_PART_SIZE);
      },
      HIL_OTA_PART_SIZE);
  size_t partCount =
      (otaSourceFile.size() + HIL_OTA_PART_SIZE - 1) / HIL_OTA_PART_SIZE;
  otaOfferTask = mesh.offerOTA(otaSourceRole, HIL_OTA_HARDWARE, otaSourceMd5,
                               partCount, true);
  JsonDocument doc;
  doc["evt"] = "ota_offered";
  doc["md5"] = otaSourceMd5;
  doc["parts"] = partCount;
  emitEvent(doc);
}

void handleNodeList() {
  JsonDocument doc;
  doc["evt"] = "node_list";
  JsonArray nodes = doc["nodes"].to<JsonArray>();
  for (auto id : mesh.getNodeList(false)) nodes.add(id);
  emitEvent(doc);
}

void deliveryEvent(uint32_t nodeId, bool delivered, uint32_t latencyMs) {
  JsonDocument doc;
  doc["evt"] = "ack";
  doc["node"] = nodeId;
  doc["delivered"] = delivered;
  doc["latencyMs"] = latencyMs;
  emitEvent(doc);
}

void emitSendResult(bool ok) {
  JsonDocument doc;
  doc["evt"] = "send_result";
  doc["ok"] = ok;
  emitEvent(doc);
}

void registerMeshCallbacks() {
  mesh.onReceive(&receivedCallback);
  mesh.onNewConnection(&newConnectionCallback);
}

void emitGatewayStatus(const char *eventName, bool initialized = true) {
  JsonDocument doc;
  doc["evt"] = eventName;
  doc["initialized"] = initialized;
  doc["isBridge"] = mesh.isBridge();
  doc["isSharedGateway"] = mesh.isSharedGatewayMode();
  doc["hasInternet"] = mesh.hasInternetConnection();
  doc["hasLocalInternet"] = mesh.hasLocalInternet();
  doc["wifiStatus"] = (int)WiFi.status();
  doc["localIP"] = WiFi.localIP().toString();
  doc["channel"] = WiFi.channel();
  const uint32_t primaryGateway = mesh.getPrimaryGateway();
  doc["primaryGateway"] = primaryGateway;
  JsonArray gateways = doc["gateways"].to<JsonArray>();
  for (auto gatewayId : mesh.getGateways()) gateways.add(gatewayId);
  // How long ago this node last heard the primary gateway's status, or -1 when
  // it has no record of it. The library trusts a status for bridgeTimeoutMs
  // (60 s); a row that must act inside that window anchors on this. The
  // `mesh_log` line saying the same is diagnostic only -- the host capture
  // keeps it in the raw log and never delivers it as an event.
  long primaryGatewayAgeMs = -1;
  for (const auto &bridge : mesh.getBridges()) {
    if (bridge.nodeId == primaryGateway) {
      primaryGatewayAgeMs = static_cast<long>(millis() - bridge.lastSeen);
      break;
    }
  }
  doc["primaryGatewayAgeMs"] = primaryGatewayAgeMs;
  emitEvent(doc);
}

void startRegularMesh() {
  rolePreferences.begin("hil-role", false);
  rolePreferences.remove("bridge");
  rolePreferences.remove("sharedGateway");
  rolePreferences.remove("failover");
  rolePreferences.remove("ssid");
  rolePreferences.remove("password");
  rolePreferences.remove("healthHost");
  rolePreferences.remove("healthPort");
  rolePreferences.putBool("reportMesh", true);
  rolePreferences.end();
  JsonDocument doc;
  doc["evt"] = "mesh_restarting";
  emitEvent(doc);
  consoleFlush();
  restartAgent();
}

void handleMeshConfigure(JsonDocument &cmd) {
  String prefix = cmd["prefix"].as<String>();
  String password = cmd["password"].as<String>();
  if (prefix.length() == 0 || prefix.length() > 31 || password.length() < 8) {
    emitError("mesh_configure requires a 1..31 character prefix and 8+ character password");
    return;
  }
  rolePreferences.begin("hil-role", false);
  rolePreferences.remove("bridge");
  rolePreferences.remove("sharedGateway");
  rolePreferences.remove("failover");
  rolePreferences.remove("ssid");
  rolePreferences.remove("password");
  rolePreferences.remove("healthHost");
  rolePreferences.remove("healthPort");
  rolePreferences.putString("meshSsid", prefix);
  rolePreferences.putString("meshPass", password);
  rolePreferences.putBool("reportMesh", true);
  rolePreferences.end();
  JsonDocument doc;
  doc["evt"] = "mesh_restarting";
  doc["meshPrefix"] = prefix;
  emitEvent(doc);
  consoleFlush();
  restartAgent();
}

void handleGatewayStart(JsonDocument &cmd) {
  String ssid = cmd["ssid"].as<String>();
  String password = cmd["password"].as<String>();
  if (ssid.length() == 0 || password.length() < 8) {
    emitError("gateway_start requires ssid and an 8+ character password");
    return;
  }
  rolePreferences.begin("hil-role", false);
  rolePreferences.putBool("bridge", true);
  rolePreferences.remove("sharedGateway");
  rolePreferences.remove("failover");
  rolePreferences.putString("ssid", ssid);
  rolePreferences.putString("password", password);
  rolePreferences.end();
  JsonDocument doc;
  doc["evt"] = "gateway_restarting";
  doc["ssidLength"] = ssid.length();
  doc["passwordLength"] = password.length();
  emitEvent(doc);
  consoleFlush();
  restartAgent();
}
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
void loop() {
  if (stallUntil != 0) {
    if ((int32_t)(millis() - stallUntil) < 0) {
      delay(5);  // deliberately NOT servicing mesh.update() or serial
      return;
    }
    stallUntil = 0;
  }
  mesh.update();
#ifdef ESP8266
  // The ESP8266 is specified for small meshes, or as a leaf in larger ones:
  // as an interior node of a seven-node mesh it runs at 10–13 KB free, and
  // an 8 KB package or an OTA part can then fail to allocate. That is the
  // part's limit, not a defect, and the rig must record when a run has put
  // the board outside its envelope — so the condition is a structured
  // event, not only the library's ERROR line. Computed here rather than
  // read from the library so this agent builds against any painlessMesh
  // ref the farm is asked to validate.
  static uint32_t capacityCheckedAt = 0;
  if (millis() - capacityCheckedAt > 30000) {
    capacityCheckedAt = millis();
    size_t children = 0;
    for (auto &sub : mesh.subs) {
      if (sub && sub->connected() && !sub->station) ++children;
    }
    uint32_t freeHeap = ESP.getFreeHeap();
    if (freeHeap < 12 * 1024 && children > 1) {
      JsonDocument doc;
      doc["evt"] = "capacity_warning";
      doc["freeHeap"] = freeHeap;
      doc["apChildren"] = children;
      doc["spec"] = "esp8266: leaf only in meshes this size";
      emitEvent(doc);
    }
  }
#endif
  // Commands first, then diagnostics, and only while nothing is waiting to be
  // read. Draining before pumping let a burst of scan logging sit in front of
  // a command that had already arrived.
  pumpSerial();
#ifdef ESP32
  if (!consoleHasInput()) drainMeshLog();
#endif
}

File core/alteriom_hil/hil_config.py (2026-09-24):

#!/usr/bin/env python3
"""Load, validate, and materialize the HIL service configuration."""

from __future__ import annotations

import json
import os
import re
import tempfile
from pathlib import Path

import yaml

# A farm host keeps it in /etc/alteriom-hil. A portal in a container has its
# own, mounted where the deployment says (ALTERIOM_HIL_CONFIG): the settings a
# portal decides with -- quarantine, retention -- are read from it.
CONFIG_PATH = Path(os.environ.get("ALTERIOM_HIL_CONFIG") or "/etc/alteriom-hil/config.yaml")
RUNTIME_ENV_PATH = Path("/etc/alteriom-hil/runtime.env")
ALLOWED_KEYS = {
    "schema": None,
    "mode": None,
    "runner": {"unit": None},
    "paths": {"venv": None, "board_map": None, "inventory": None, "repo": None, "state": None},
    "health": {
        "interval_minutes": None,
        "minimum_boards": None,
        "disk_warn_percent": None,
        "disk_critical_percent": None,
    },
    "gateway": {
        "enabled": None,
        "ssid": None,
        "password_file": None,
        "endpoint": None,
        "channel": None,
    },
    "mqtt": {"enabled": None, "url": None},
    "inventory": {"auto_register": None},
    "service": {
        "enabled": None,
        "bind": None,
        "port": None,
        "token_file": None,
        "public_host": None,
    },
    "notify": {"id": None, "enabled": None, "channel": None, "webhook_url_file": None,
               "format": None, "events": None, "token_file": None, "chat_id": None},
    "queue": {"concurrency": None},
    "quarantine": {"enabled": None, "after_failures": None},
    "farm": {"mode": None, "portal_url": None, "worker_name": None, "node_key_file": None,
             "public_url": None},
    "backup": {"enabled": None, "directory": None, "keep": None, "target": None},
    "retention": {
        "enabled": None,
        "run_evidence_days": None,
        "log_days": None,
        "keep_newest_runs": None,
        "workspace_days": None,
    },
    "providers": {"callmebot": {"url_file": None, "send": None, "max_per_day": None}},
}
# What the farm tells a person about, and in which shape a webhook takes it
# (alteriom_hil.notify).
NOTIFY_EVENTS = ("queue_paused", "board_red", "host_unhealthy")
NOTIFY_FORMATS = ("slack", "discord", "json")
# The ways a farm can carry a message. Declared in alteriom_hil.notify, so a
# channel added there is configurable here without a second list.
NOTIFY_CHANNELS = ("webhook", "telegram", "callmebot")
# A Telegram chat id: a user, or a group, which is negative and longer.
CHAT_ID_PATTERN = re.compile(r"-?\d{1,20}")
NOTIFY_FORMATS
DEFAULT_BACKUP = {"enabled": True, "directory": "/var/lib/alteriom-hil/backups", "keep": 14}
# Off unless a host asks for it: deleting evidence is a decision, and a host
# upgraded into this must not start doing it on its own.
DEFAULT_RETENTION = {
    "enabled": False,
    "run_evidence_days": 90,
    "log_days": 90,
    "keep_newest_runs": 100,
    "workspace_days": 2,
}
# Off unless a host asks for it: a quarantine leaves a board out of the
# release gate's runs, and a host upgraded into this should not start doing
# that by itself.
DEFAULT_QUARANTINE = {"enabled": False, "after_failures": 2}
# How the host takes part in the farm (docs/portal-plan.md). `attached` keeps
# the standalone service -- and every CI job that submits to it -- and runs a
# node agent beside it, so a portal sees and uses the rig before anything is
# moved onto it.
FARM_MODES = ("standalone", "attached", "portal", "node")
DEFAULT_GATEWAY = {
    "enabled": False,
    "ssid": "Alteriom-HIL",
    "password_file": "/etc/alteriom-hil/gateway-wifi-password",
    "endpoint": "http://10.42.0.1:8088",
    # The 2.4 GHz channel this rig's AP runs on, and so the channel a board
    # promoted to bridge takes its mesh to. 1 is painlessMesh's own default,
    # where a mesh that has no bridge yet roots: equal, nothing splits
    # (setup-gateway-network.sh). A rig configured before this setting
    # existed has no channel and is read as 1.
    "channel": 1,
}
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

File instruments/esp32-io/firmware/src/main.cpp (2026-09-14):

// The farm's I/O instrument, on an ESP32 (esp32dev / WROOM-32).
//
// Its pins are test equipment: they press a button on a board under test,
// read its LED, measure a pulse. It speaks newline-delimited JSON on its USB
// serial port, framed like a HIL agent, and answers every command once.
//
// host -> instrument:
//   {"cmd":"info"}
//   {"cmd":"mode","ch":25,"mode":"input|pullup|pulldown|output"}
//   {"cmd":"write","ch":25,"level":1}            // makes the channel an output
//   {"cmd":"read","ch":34}
//   {"cmd":"adc","ch":34,"samples":8}
//   {"cmd":"pulse","ch":25,"level":1,"ms":100}   // level for ms, then the other
//   {"cmd":"count","ch":34,"ms":1000,"edge":"rising|falling|any"}
//   {"cmd":"wait_edge","ch":34,"edge":"any","timeoutMs":2000}
//   {"cmd":"release"}                            // every channel a plain input
//
// instrument -> host: {"evt":"<cmd>",...} for each, {"evt":"edge",...} for
// wait_edge, {"evt":"boot",...} once at start, and
// {"evt":"error","cmd":"<cmd>","error":"..."} for a command refused -- which
// did not run. A line that is not JSON is answered {"evt":"error","error":"bad
// json"}, which the host takes as permission to resend.
//
// Every channel starts as an input with no pull, and `release` puts them back:
// the one state nothing wired to it can be harmed by. A command runs to
// completion before the next is read, so `pulse`, `count` and `wait_edge`
// block for as long as they were asked to (at most ten seconds, one minute
// for wait_edge).
//
// The channel table is the farm's too (alteriom_hil.instrument.KINDS); a test
// keeps the two in agreement.

#include <Arduino.h>
#include <ArduinoJson.h>

#ifndef INSTRUMENT_SHA
#define INSTRUMENT_SHA ""
#endif

static const int PROTOCOL_VERSION = 1;
static const char *KIND = "esp32-io";

struct Channel {
  uint8_t pin;
  bool drive;
  bool pull;
  bool adc;
};

// Left out: strapping 0 2 5 12 15, console UART 1 3, flash 6-11. 34-39 are
// input-only and have no pulls.
static const Channel CHANNELS[] = {
    {4, true, true, false},   {13, true, true, false}, {14, true, true, false},
    {16, true, true, false},  {17, true, true, false}, {18, true, true, false},
    {19, true, true, false},  {21, true, true, false}, {22, true, true, false},
    {23, true, true, false},  {25, true, true, false}, {26, true, true, false},
    {27, true, true, false},  {32, true, true, true},  {33, true, true, true},
    {34, false, false, true}, {35, false, false, true}, {36, false, false, true},
    {39, false, false, true},
};
static const size_t CHANNEL_COUNT = sizeof(CHANNELS) / sizeof(CHANNELS[0]);

static volatile uint32_t edgeCount = 0;
static volatile bool edgeSeen = false;

static void IRAM_ATTR onEdge() {
  edgeCount++;
  edgeSeen = true;
}

const Channel *findChannel(int pin) {
  for (size_t i = 0; i < CHANNEL_COUNT; i++) {
    if (CHANNELS[i].pin == pin) return &CHANNELS[i];
  }
  return nullptr;
}

String macAddress() {
  const uint64_t mac = ESP.getEfuseMac();  // byte 0 is the first octet
  char text[18];
  snprintf(text, sizeof(text), "%02x:%02x:%02x:%02x:%02x:%02x", (uint8_t)(mac), (uint8_t)(mac >> 8),
           (uint8_t)(mac >> 16), (uint8_t)(mac >> 24), (uint8_t)(mac >> 32), (uint8_t)(mac >> 40));
  return String(text);
}

void send(JsonDocument &doc, JsonDocument &cmd) {
  // A host may tag a command to match its reply; echo the tag back.
  if (!cmd["seq"].isNull()) doc["seq"] = cmd["seq"];
  serializeJson(doc, Serial);
  Serial.print('\n');
}

void refuse(JsonDocument &cmd, const char *error) {
  JsonDocument doc;
  doc["evt"] = "error";
  if (cmd["cmd"].is<const char *>()) doc["cmd"] = cmd["cmd"].as<const char *>();
  doc["error"] = error;
  send(doc, cmd);
}

void releaseAll() {
  for (size_t i = 0; i < CHANNEL_COUNT; i++) {
    detachInterrupt(digitalPinToInterrupt(CHANNELS[i].pin));
    pinMode(CHANNELS[i].pin, INPUT);
  }
}

void describe(JsonDocument &doc) {
  doc["role"] = "instrument";
  doc["kind"] = KIND;
  doc["protocol"] = PROTOCOL_VERSION;
  doc["fw"] = INSTRUMENT_SHA;
  doc["target"] = "esp32";
  doc["mac"] = macAddress();
}

// The channel a command names, or nullptr after refusing it.
const Channel *channelFor(JsonDocument &cmd) {
  if (!cmd["ch"].is<int>()) {
    refuse(cmd, "ch must be a channel number");
    return nullptr;
  }
  const Channel *channel = findChannel(cmd["ch"].as<int>());
  if (!channel) refuse(cmd, "no such channel");
  return channel;
}

int interruptMode(JsonDocument &cmd, const char *fallback) {
  const char *edge = cmd["edge"] | fallback;
  if (strcmp(edge, "rising") == 0) return RISING;
  if (strcmp(edge, "falling") == 0) return FALLING;
  if (strcmp(edge, "any") == 0) return CHANGE;
  return -1;
}
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

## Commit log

2026-08-04 feat: MVP rig software — HAL, runner kit, painlessMesh HIL suite, CI (#1 #2 #3 #4)
    - hal/alteriom_hil: board map, flash (pio/esptool), threaded JSON serial
    capture, power control (uhubctl + noop), protocol client with
    event-retaining wait_for, sim backend mirroring the agent protocol,
    pytest fixtures with serial-log artifact dumping. 13 unit tests.
    - runner/: setup-runner.sh, udev rules (port-path pinned symlinks),
    board-map.example.yaml.
    - suites/painlessmesh: HIL agent firmware (JSON serial REPL over
    painlessMesh incl. the #379 delivery-confirmation API; stall command
    for real ACK-timeout scenarios; PAINLESSMESH_REF-pinned build),
    flash_all.py, pytest scenarios: mesh format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
    [main.cpp]
2026-08-04 feat(mounts): printable mounting-plate STLs + per-Pi scaling analysis
    Three parametric tiles generated by a stdlib-only Python script (edit
    dims there, rerun to regenerate — STLs are build artifacts kept in-tree
    for direct printing):
    - esp32-board-tile: 29 mm locating channel + zip-tie stations with
    under-tile grooves, so hole-less devkit clones of any 44-55 mm length
    mount identically
    - pi5-tile: Pi 4/5 58x49 pattern on 6 mm self-tap bosses
    - hub-strap-tile: universal strap plate for the hub (relay boards later)
    Tile-per-board is the scalability mechanism: growth is additive (print
    tile, screw to plank at chosen pitch), never a plate redesign.
    Blueprint gains §8: per-Pi ceilings (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
    [esp32-board-tile.stl, hub-strap-tile.stl, pi5-tile.stl]
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2026-09-03 docs(hardware): per-board power-cut relay wiring diagram and spec
    The installed hub gangs its downstream ports, so power.recovery skips on
    every physical run. This specifies the 8-channel 12 V relay module as a
    second, independent power path: each relay switches only the 5 V core of
    one board's USB cable, through the NC contact so a released relay keeps
    the board powered, driven from Pi 5 GPIOs that default to pull-down.
    - docs/relay-power-wiring.md: design decisions, parts, jumper settings
    (high-level trigger; why low-level cannot work with 12 V + 3.3 V),
    channel map (relay terminal / hub port / udev name / header pin / GPIO),
    wiring order, electrical acceptance tests, hazards, and t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
    [render_relay_wiring.py]
2026-09-03 docs(hardware): use the full `pinctrl set <gpio> op dh|dl` form everywhere
    Review nit: the restore commands in the channel map, the acceptance-test
    loop, and the drive-test line rendered into the diagram omitted the `op`
    mode. The short form only works once the pin is already an output; the
    full form is unambiguous and matches the `pinctrl get` expectation.
    Claude-Session: https://claude.ai/code/session_011hEhtEnQehyLaiB5jWXxQG
    [render_relay_wiring.py]
2026-09-03 docs(hardware): rig ports are USB-C pigtail pairs; add C5/C6/8266 families
    Rework the relay wiring for the pigtail kit actually on hand: each rig
    port is a USB-C female pigtail joined with wire nuts to a USB-C male
    pigtail, with only the red 5 V wire routed through the relay. The hub
    cable and the board stay unmodified, so any board family can sit on any
    of the eight ports.
    - Diagram: eight hub ports feeding eight rig ports, pigtail pair and
    wire-nut joins per column, example family placement including
    ESP32-C5, ESP32-C6 and ESP8266, identity-by-MAC noted per board.
    - Doc: parts list for the pigtail kit, C→micro-B adapters and unmodified
    cables; per-family table of which USB socket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
    [render_relay_wiring.py]
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2026-09-03 hardware: address review — exact rack pitch, 8-port hub model, print-size claims
    - rack modules at x 6..166 and 166..326: no 1 mm overlap, slot 4→5 is
    40 mm like every other gap; the rear wall's notches are now computed
    from the real slot positions of both segments instead of assuming
    wall coordinates 20/60/100/140.
    - render_rig.hub_node models 8 ports; render_chassis fails fast when the
    hub model has fewer port anchors than rack slots instead of wrapping.
    - bring-up checklist no longer says a switchable hub is what enables
    power-cut tests; the relay chassis does, uhubctl is a second path.
    - README and viewer: "no printed part longer than 178 mm" (the end
    walls) instead of "u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
    [deck-wall-rear.stl]
2026-09-04 hal: discovery reads every esptool version; add ESP32-C5, C6, and ESP8266 targets
    Discovery failed on the three boards just plugged in ("cannot identify
    /dev/ttyACM2 from esptool output") because probe_port only knew three chip
    names and a 6-byte MAC: the ESP8266 never matched the chip regex, and the C5
    and C6 print an 8-byte EUI-64 that the MAC regex rejected.
    Discovery now parses esptool v4 and v5 output ("Detecting chip type...",
    "Chip is", "Chip type:", "Connected to ... on"), reduces marketing names
    (ESP32-D0WD-V3, PICO-D4, QFN40) to the silicon family, takes the 6-byte base
    MAC (from the BASE MAC line, or derived from the EUI-64), records whether a
    port is the chip's own USB-Serial/JT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
    [main.cpp]
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2026-09-04 firmware: the agent speaks on both consoles, so either USB socket works
    The C5 and C6 devkits carry two USB-C sockets — the chip's own USB-Serial/JTAG
    and a UART bridge — and the firmware cannot know which one is cabled. With
    ARDUINO_USB_CDC_ON_BOOT the Arduino `Serial` is the native USB CDC while
    ESP-IDF's logging goes to UART0, so a board plugged into its UART socket
    emitted IDF chatter and none of the protocol. Preflight saw a silent port and
    reported `timed out waiting for info reply`, which reads as a dead board:
    FAILED: esp32-c6-14b4 (esp32-c6): TimeoutWaitingFor: timed out waiting
    for info reply
    --- last serial lines ---
    (nothing)
    The board was neither dead nor s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
    [main.cpp]
2026-09-05 hal: give the post-restart info reply the same budget as the restart
    configure_mesh allowed 30s for `mesh_started` and then 10s for the `info`
    that follows. An ESP32-C5 answers `info` about fifteen seconds after its
    restart — roughly ten after `mesh_started` — so the window closed exactly at
    the edge and the C5 failed here on every run while every other family
    cleared it. That is why it looked like flakiness and behaved like a wall.
    Measured rather than guessed: polling the board after a mesh_configure gave
    answered=False at t+5.1s and t+12.2s, answered=True at t+14.5s. The board was
    never wedged, only slower than it was allowed to be.
    Also bounds pumpConsole to 2048 bytes per call. Th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
    [main.cpp]
2026-09-05 firmware: regular nodes declare the mesh contains a root
    painlessMesh asks every node of a mesh that is meant to contain a bridge to
    call setContainsRoot(); the flag is local and never propagated. The agent set
    it nowhere, so on a follower `shouldContainRoot && !isRooted` was always
    false, and the library's "connected but orphaned" recovery could never fire.
    That is half of why a bridge start stranded nodes on the old channel. The
    other half is in painlessMesh itself (fix/stranded-followers-after-bridge-
    channel-move): channel re-detection excluded connected nodes entirely and
    picked a channel by scan order. This flag is what lets that fix reach a node
    that is still attached to a partition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
    [main.cpp]
2026-09-05 firmware: regular nodes frame painlessMesh's connection log as mesh_log events
    The failover failure in the first sweep on the channel fix had the sender
    associated-without-an-address for eighty seconds with nothing on its
    serial log but one "wifi scan failed": regular nodes ran the library at
    ERROR only, because painlessMesh prints from the Wi-Fi event task and a
    line written there lands in the middle of a JSON frame.
    painlessMesh now offers a log sink (fix/stranded-followers PR). The agent
    installs one on ESP32-family regular nodes: lines are queued in a small
    ring under a critical section and loop() frames them between protocol
    frames as {"evt":"mesh_log","level":...,"line":...}, two per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
    [main.cpp]
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2026-09-05 agent+hal: commands outrank diagnostics, and a wedged board is reset instead of poisoning every run
    Two independent faults, both of which made the rig look flaky.
    A board that hard-hangs stays hung. The ESP8266 was found silent on an
    open port — no output, no reply to `info`, no watchdog, no crash dump —
    and one RTS/DTR pulse brought it straight back. Nothing in the farm did
    that, so every run after the hang inherited a dead board and failed
    somewhere different depending on which test needed it. That reads like
    flakiness and is not. The hardware bank now checks each board answers
    before anything is measured, resets the silent ones once, and names any
    that stay dead rather than letting a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
    [main.cpp]
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2026-09-05 agent: stamp every mesh_log line with when it was produced
    Reading a failover failure meant ordering radio events against protocol
    events, and mesh_log frames carried no time at all. Draining is
    deliberately deferred behind commands, so a drain-time stamp would not
    have helped either — the stamp is taken in the sink, when the line was
    produced.
    This is the difference between "the node logged both 'I WON! Promoting
    to bridge' and 'no root in sight, following another channel'" and knowing
    which came first, which is the whole question.
    [main.cpp]
2026-09-05 agent: capture the bridge and gateway diagnostics on regular nodes
    GENERAL is where painlessMesh logs "Broadcasting status" and "Bridge
    status received from %u" — the two lines that separate "the promoted
    bridge never announced itself" from "it announced and nobody heard".
    Every failover failure so far has come down to that question and neither
    line was captured.
    It was unusable before because a per-tick scheduler trace also sat at
    GENERAL; that is DEBUG now (painlessMesh#429). With diagnostics no
    longer flushing and draining only when no command is waiting, the extra
    volume is affordable — the drop counter read zero on all seven boards
    across a full suite at the current levels, and it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
    [main.cpp]
2026-09-06 agent+hal: a swallowed command is reported and resent; a module fixture failing no longer ends the suite
    Run 2 of the latest sweep lost the shared-gateway module and, with it,
    the soak measurement, to a single command the ESP8266 never acknowledged
    — and never reported. Its own log shows the previous role change arriving
    corrupted, being reported as "bad json", resent and acknowledged; the
    next command produced nothing at all. Two ways a frame vanished without a
    word: its tail, newline included, never arrived, so the head sat in the
    line buffer until a later newline fused the two; or String::concat failed
    on a board down to 8 K of heap, which keeps the old contents and returns
    false, and t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
    [main.cpp]
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2026-09-06 suite+agent: the ESP8266 is held to its specified envelope, and says so itself
    Product decision: the ESP8266 is specified for small meshes, or as a leaf
    in larger ones. Measured on this rig as an interior node of the seven-node
    mesh it runs at 10–13 KB free — a working set that tracks its live
    connections and the traffic through them, recovering on every reboot and
    falling as peers attach, not a leak (the per-test curve is in
    extra.board_heap). Below about 8 KB an 8 KB package or an OTA part fails
    to allocate. That is hardware capacity, not a library or farm fault, and
    the rig now reads it as such.
    The soak holds the ESP8266 to a floor (8 KB) rather than to 75 % of
    wherever it started;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
    [main.cpp]
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2026-09-07 firmware: every reboot the host asks for stops the mesh first
    The agent rebooted straight into its new role. A bridge that leaves that
    way says nothing, and on the rig the backup held it healthy until its
    last status aged out: the failover test's 120 s promotion deadline expired
    first whenever the backup had booted beside the live primary. painlessMesh
    now announces a bridge stepping down from stop(), so the six reboot tails
    become one restartAgent() that stops the mesh, waits for the announcement
    to leave, and restarts.
    [main.cpp]
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2026-09-11 suite: anchor the stale-gateway row on an age the agent reports, not a diagnostic log line (#85)
    Gate run 34631433708 on painlessMesh 9c22a97 (the 2.0.3 release head) passed
    37 of 39 rows and failed only gateway.stale_after_reboot, before it did
    anything: it timed out waiting for the sender's "Bridge status received from
    <bridge>" line. That line is a mesh_log event, which the host capture treats
    as diagnostic -- kept in the raw log, never put on the event queue wait_for
    reads -- so the wait could not match on any run. The row passed review and
    collection; only the rig could show it was blind. The previous clean run
    (34625328013) predates the row reaching main.
    The agent now reports primary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
    [main.cpp]
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2026-09-12 canary: the farm's own firmware, and the suite that asks it about the rig (#88)
    Artifact-first, step 3: the firmware, the suite and the profile.
    Every other profile here answers "is this project's firmware good on this
    hardware". This one answers "is this hardware good", and it is the farm's
    own question -- so the firmware is the farm's own, carrying nothing from
    painlessMesh and nothing from a consumer. A red canary is never somebody's
    regression: it is an ESP, a cable, a hub, or the rig's access point, broker
    or uplink.
    canary/firmware/ is the Arduino core, ESP-IDF and ArduinoJson and nothing
    else (asserted, not trusted: a test reads its includes and its one pinned
    dependency). It speaks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
    [main.cpp]
2026-09-12 canary: make it compile, and compile it before a release installs it (#93)
    Three farm deploys are red, and the reason is an ArduinoJson type error in
    the canary -- on the job whose whole purpose is to say the farm is healthy:
    error: operands to ?: have different types 'MemberProxy<...>' and
    'const char [1]'
    const char *name = cmd["cmd"].is<const char *>() ? cmd["cmd"] : "";
    `doc["k"]` is a MemberProxy, not a value, and a ternary cannot unify one
    with a `const char *`. `|` is ArduinoJson's own idiom for "this, or a
    default when it is missing or the wrong type": shorter than the check it
    replaces and it reads the key once. The two places that keep an explicit
    check are the two whose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
    [main.cpp]
2026-09-12 canary: what its first run on the rig found (#94)
    The canary flashed and answered on all seven boards -- the bundle built on
    the simulation host, `build:skipped`, nothing compiled on the Pi -- and then
    found three bugs, two of them in itself. Which is the job.
    **A kilobyte-long command did not survive a native USB console.** The serial
    check sends 1033 bytes on purpose. The ESP8266 and the classic ESP32, both
    on UART bridges, echoed every one; the S3, the C3 and the C5 each answered
    `{"evt":"error","error":"bad json"}` to a truncated frame and then timed out.
    A native USB-Serial/JTAG console starts with a 256-byte receive buffer, and
    the loop slept two milliseconds in the middle of the comm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
    [main.cpp]
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2026-09-14 gateway: one call reaches the destination once, a 429 retry waits, and the reply reaches the application (#125)
    * gateway: one call reaches the destination once, a 429 retry waits, and the reply reaches the application
    The rig saw one sendToInternet() call issued four times after a read
    timeout, and the transport-error row passed because it only read the
    verdict. The probe's ledger now counts requests per tag and records their
    X-Request-Id, and /retry-after/{s} refuses a tag once with 429.
    New rows: internet.single_delivery (a slow destination sees one request)
    and internet.retry_after (the retry is not early and keeps one request id).
    internet.service_semantics now holds painlessMesh #464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
    [main.cpp]
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2026-09-16 canary: the farm's own firmware is the Rig Health Check, and it has a version (#145)
    * canary: the farm's own firmware is the Rig Health Check, and it has a version
    Two things a person reading the dashboard could not do: say what the firmware
    in `canary/` is for without being told, and say which build of it checked a
    board.
    **The name.** "Farm canary" named the alarm, not the job. The firmware flashes
    each ESP and checks that it boots, that its serial path is clean, that its
    flash keeps a value, that the rig can restart it, that its radio sees and
    joins the rig, and that the rig's uplink and broker answer it -- which is what
    the Rigs page already calls Check health and what the API already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
    [main.cpp]
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2026-09-21 painlessmesh: a node that crashes at boot is named, and every node reports its listener (#184)
    * painlessmesh: a node that crashes at boot is named, and every node reports its listener
    painlessMesh #466: an uninitialised listener pointer crashed a node inside
    init() before it served a connection. On this rig that would have read as
    "the mesh never formed" -- a timeout in the mesh fixture -- with the crash
    and the boot loop behind it visible only to whoever grepped the serial log
    afterwards. The bug-to-capability rule says a user report earns a row that
    would have caught it here first; this is that row, and one beside it.
    node.boot_integrity runs on the bank alone, before the mesh fixture,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
    [main.cpp]
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2026-09-22 allocation: a family that is away is a gap, not a failed run (#222)
    The Alteriom firmware nightly has failed every night since 2026-09-17 with
    "Not enough boards for this profile": the ESP32-S3 is off the rig, its
    `needs` entry was required, and discover refused the run before it touched
    anything. A red run that said nothing about the firmware, and no validation
    at all for the five families that *are* connected.
    A profile's `needs` entry may now say `optional: true`. Such a need asks the
    rig only for the boards of that family it has: an absent one is done without
    rather than refused. It is about absence and nothing else -- a board that is
    connected and busy is waited for exactly as a requir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
    [allocation.py, profiles.py, report.py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]
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2026-09-22 public: what goes out says nothing about this farm in particular (#228)
    `core/` and `rig/` become somebody else's repository, and they were
    carrying our names: the Pis, the person who runs them, the portal we
    happen to run at the address we happen to use.
    Gone. The example configuration a rig owner copies is somebody else's --
    its paths, its runner unit, its backup target, its worker name -- and
    still a valid document, because it is validated against the schema and
    by the service. The join script's usage says `https://<your-portal>`.
    The rig-view schema's `$id` is the public repository's. The dashboard
    no longer names the ConfigMap our deployment mounts, only the file the
    portal read. And t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
    [admin_cli.py, api_keys.py, board_registry.py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]
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2026-09-23 public: nothing in what goes out is about this farm, and the lift rehearses (#237)
    Two halves of 14c, and both are about the one thing that cannot be taken
    back: a public repository's history.
    The four comments that named our private consumer now name a consumer.
    Each was explaining why a shape exists -- a one-board profile, a private
    repository to clone, an image that nearly did not fit a 4 MB slot -- and
    each explains it as well without the name. The scrub ratchet is down to a
    single known name: the sshd drop-in in harden-pi.sh, which is named for
    the project and cannot be renamed on a rig that already has the old one.
    And the lift is written down. `runner/ci/lift-rig.sh` holds the path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
    [report.py, rig_manager.py]
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2026-09-24 rig: a reply that arrived unreadable is asked for again when the command is safe to repeat (#15)
    A scan check timed out at 45 s with the answer in the serial log: the
    reply's first 32 characters arrived as 64 undecodable bytes and the tail
    intact, so the line yielded no event (farm run be46491e, esp32-fde4).
    The board had answered in 6 s as always, was neither reset nor slow, and
    the timeout was not tight -- measured scans are 2.2 s to 12.3 s across
    the families. The rig just could not tell a damaged reply from silence.
    The capture now frames a line with undecodable bytes and no event as its
    own {"evt":"unreadable"}, keeping the line in the raw log as it came, and
    send_cmd_awaiting(idempote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
    [protocol.py, serial_capture.py]
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2026-09-24 The token, seen whole: kind, expiry, source, reach, and what it may do (#20)
    * The token, seen whole: kind, expiry, source, reach, and what it may do
    Adding a project with a token scoped to another repository failed with a
    bare 404, and nothing said what the token is, whether it still works,
    what it may do or which repositories it reaches. GET /api/v1/github and
    the GitHub card now say: kind (by prefix), who GitHub says it is, when it
    expires (the expiration header; the Overview warns two weeks ahead),
    where it came from (this page, or the host's file), the repositories it
    reaches, and per project whether it sees the repository, reads its code
    and lists its Actions artifacts. POST /api/v1/g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
    [github_access.py, rig_manager.py]
2026-09-24 The GitHub card as a status block; the portal knows a rig's GitHub (#22)
    Facts (Status, Account, Token, Expires, Set, Repositories), a per-project
    table (sees it, reads its code, fetches its bundles, with what it needs
    under the project's name), and buttons: Check again, Details, Replace
    token, Forget it. The token form appears only after Replace. Details is
    a dialog with the whole picture: the private repositories the token was
    given, the public ones it sees, a classic token's scopes, what GitHub
    refused and why, where the token lives -- never the token.
    The rig's page carries a GitHub fact, here from its own summary and on a
    portal from what the rig reports: the node's hello and heartbeat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
    [farm_node.py, jobstore.py]
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2026-09-25 A run that chose families gets the boards of those families and no other (#30)
    The Rig example on a bench of two esp32, an esp8266 and an esp32-c5, with
    a bundle built for esp32 and esp8266, was refused at discover: "Missing
    artifact families: esp32-c5". The profile takes the whole bench, so the
    run was handed a board it never asked for and then blamed for lacking its
    image. A project that declares no `needs` now runs on the boards of the
    families the run chose -- the ones its bundle carries and the person kept
    -- and leaves the rest of the bench alone, saying so in the log. Every
    family chosen, or none named, is the bench unchanged; families that match
    no connected board are refused by name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
    [rig_manager.py]
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2026-09-27 Review fixes: scoped bundle totals, cancel race, streaming limits, dashboard routing (#42)
    From the 2026-09-26 deep review of core/ and rig/, each with a test:
    - The bundle list's totals (profiles, count, bytes, pinned, prune) are
    counted over what the caller may see; an account read every private
    project's name off `profiles`.
    - A cancel only marks a still-queued run cancelled (`cancel_if_queued`); one
    the dispatcher claimed first is interrupted instead of relabelled.
    - A negative or non-numeric Content-Length is a 400, not an unbounded read.
    - A rig's /view is not found for a caller who may not see the rig; a pending
    rig and a missing one say the same thing.
    - Adding a rig answers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
    [backup.py, jobstore.py, rig_manager.py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]
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
